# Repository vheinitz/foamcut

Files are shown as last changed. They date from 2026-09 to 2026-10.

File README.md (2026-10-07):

# foamcut — GT2560 XYUV hot wire cutter, bring-up project

A test bootstrap for a 4 axis hot wire foam cutter running on a Geeetech
GT2560. Two independent towers, four axes: **X/Y** on the left tower, **U/V**
on the right. Firmware is [grbl-Mega-5X](https://github.com/fra589/grbl-Mega-5X)
with a GT2560 pin map written for this project.

Nothing here needs the machine to exist yet — `make test` runs 77 checks
offline, including a cross-check that the two firmwares' pin maps describe the
same physical board.

```
make deps && make test          # offline
make grbl-flash                 # the one firmware, docs/bringup.md step 3
foamcut settings apply config/grbl_settings_foamcut.txt
foamcut setup                        # step 4: measure, no limit switches needed
foamcut run gcode/02_taper.nc
```

Follow **[docs/bringup.md](docs/bringup.md)** in order. It is written so that a
failure at any step can only have been caused by that step.

## Why not the obvious options

**Not RAMPS.** The GT2560 is a Mega 2560 with the driver sockets and MOSFETs on
the same PCB, but it is *not* RAMPS pin compatible. `motor_test/motor_test.ino`
in this directory is an example of the failure mode: it drives RAMPS pin
numbers (D54/D55/D38 for X) on a board whose X driver is on D25/D23/D27, so
nothing moves and nothing reports an error. The correct plain-Arduino sketch
is [`gt2560_motortest/`](gt2560_motortest/). See
[docs/gt2560_pinout.md](docs/gt2560_pinout.md).

**Not Marlin.** Marlin plans one E axis per move, so `X Y Z E` gives you four
simultaneous axes only if you accept that the fourth is an extruder with
extruder semantics — `M92`/`T0`/`M83`, no `U`/`V` letters, no `G28` per tower,
and no G-code generator that emits it. The `Marlin/` tree here is configured
that way (`EXTRUDERS 2`, `BOARD_GT2560_REV_A_PLUS`) and is kept as a reference,
but a foam cutter wants XYUV, not XYZE.

**Not the reference repo's firmware.** [rahulsarchive/4AxisFoamCutter](https://github.com/rahulsarchive/4AxisFoamCutter)
is a good build log and its notes on wire temperature, feed rate and G-code
generators are worth reading. It contains no firmware source, though — it
points at a grbl 0.8c2 fork for Mega/RAMPS. grbl-Mega-5X is the maintained
descendant of that idea, handles up to 6 axes, and lets the axis letters be
renamed, which is how this build gets real `U` and `V` words.

## Layout

| path | what |
|---|---|
| `firmware/hwtest/` | Bring-up fallback only: bit-bangs pins without a planner, for a board that shows no sign of life. Normal operation runs grbl exclusively. |
| `gt2560_motortest/` | Plain Arduino `.ino` with the correct GT2560 pins: pick X/Y/Z/U on the console, set microstepping, bounce motors. No PlatformIO needed. |
| `firmware/grbl5x/` | `build.sh` fetches grbl-Mega-5X, `configure.py` applies the XYUV/GT2560 overlay, then it builds and flashes. Every patch is anchored and verified, so an upstream change fails loudly instead of producing a firmware with a wrong pin map. |
| `firmware/grbl5x/overlay/cpu_map_gt2560.h` | the GT2560 pin map for grbl |
| `config/grbl_settings_foamcut.txt` | `$` settings, commented, with `MACHINE` marking every value you must measure |
| `host/` | the `foamcut` command line tool and its tests |
| `host/foamcut/qt/` | the PyQt6 interface; the masks are Qt Designer files in `qt/ui/*.ui` (loaded with `uic.loadUi`), dynamic widgets such as the mm canvases go into named placeholder layouts/splitters; `config/ui_state.json` remembers the last wing values, program and page |
| `gcode/` | test programs, from a single axis bounce to a tapered block |
| `airfoil/` | 295 airfoil `.dat` files (UIUC database via swarfer.co.za); instead of a file name, a four digit NACA number (`2412`) or its three numbers (`2 40 12` = camber %, position %, thickness %) can be typed and is computed |
| `config/beispiel.wing` | wing spec template, matches the measured travel |
| `config/beispiel.shape` | free-shape spec template (fuselage segment, ring) |
| `config/beispiel.contour`, `beispiel.svg` | SVG outline spec: ring, triangle and an "A" with its hole |
| `config/beispiel.slices`, `beispiel.stl` | slab spec: a 200 mm fuselage body in 40 mm slices |
| `docs/` | pinout and bring-up checklist |

## The `foamcut` tool

Two ways to run it, both identical:

```bash
./foamcut probe                      # wrapper in the checkout, no install needed
pip install --user -e host      # once; then plain `foamcut probe` from anywhere
```

```
foamcut check FILE          validate G-code offline: unsupported codes, missing
                       feeds, Z words on an XYUV machine, extents, run time,
                       and travel against config/machine.json
foamcut setup               measure the machine: axis mapping, steps/mm, direction,
                       manual reference, travel  -> config/machine.json
foamcut ref                 manual referencing after every power-up (no switches)
foamcut home                homing on the switches, work origin = switch + offset
foamcut homing show|set     limit switch config: NO/NC, pull-off, per-axis offset
                       and length (typed, not driven); saved in machine.json
foamcut jogpad              keyboard jogging
foamcut gui                 mouse jog pad, reference/travel buttons, hot wire,
                       load + play a G-code file with pause/stop
foamcut sim FILE       both carriage paths drawn turtle-style, no hardware
                       (also in the GUI: "Simulation" next to Start)
foamcut wing SPEC.wing      wing panel: root/tip airfoil + chords, panel length,
                       sweep, washout, mirror -> one-pass XYUV G-code
                       (root always at the fixed-wire tower, `machine set --wire-fixed`;
                       block face and table top are the anchors, lead-in runs
                       inside the foam, margins give the minimal block, the
                       tool reports the allowed table height range and extent;
                       chords from area + taper; optional aileron hinge cut)
                       (GUI "Flügel…": form with validated fields, live preview,
                       stale-program warning; foamcut wing --template for the text form)
foamcut shape SPEC.shape    free shape in one pass: rounded rectangle / triangle /
                       circle / ellipse on each side, disc or ring (slit at the
                       rear), same placement as wings (GUI page "Formen";
                       foamcut shape --template)
foamcut contour SPEC.contour  outlines of an SVG (letters, silhouettes, sketches from
                       Inkscape) cut prismatically, X=U / Y=V: kerf, slits to holes,
                       several pieces routed around each other (GUI page "Kontur";
                       foamcut contour --template)
foamcut wing|shape SPEC --stl [FILE]  also write the part as a body (STL),
                       spar slots and holes included, ready to be sliced into ribs
foamcut slices SPEC.slices  one slab of an STL body: side A = section at the slab's
                       start, side B at its end, lofted (smooth stack instead of
                       steps); or prismatic through the middle. Fuselages, big
                       wings from foam slices on spars (GUI page "Scheiben")
foamcut esp ls|put|start|status|pause|resume|abort
                       programs held by an ESP32 running ESP3D in front of the
                       board (docs/esp32.md); --port tcp://host uses its bridge
foamcut nest LIST.batch     several saved parts stacked in one block, one program
                       (GUI page "Schachteln"; pairs: mirror-image panel nested
                       thin-over-thick; wire travels behind the block face)
foamcut gen square|taper|bounce
foamcut selftest            move every axis out and back, verify it came home
foamcut settings dump|apply
foamcut jog AXIS DIST
foamcut wire 0..255
foamcut run FILE            stream, stopping on the exact line that failed
foamcut console
```

`check` and `gen` need no hardware. `check`, `run` and the GUI translate
generator output on the fly (`foamcut convert` writes the result to a file):

| generator | axis letters | handled |
|---|---|---|
| hotwireairfoil.coolpixx.de | `X Y A Z` (A horizontal, Z vertical) | A→U, Z→V, `G64` dropped, `F` added after `G94`, `M3 S1` → real wire power |
| Jedicut, WingGcode | `X Y U V` | unsupported header codes reported |
| LinuxCNC style | `X Y Z A` | `--format XYZA` |

`G93` inverse time feed is passed through — grbl supports it.

## Two things that will bite you

**The bed MOSFET cannot drive the wire under grbl.** D4 is on timer 0, which
grbl uses for the step pulse reset interrupt. The wire PWM is on D3 (timer 3)
instead — a hotend-sized MOSFET, about 40 W. For a metre of nichrome, use D3 to
gate an external MOSFET and keep the current off the board.

**The feed rate is a four axis vector.** With `N_AXIS_LINEAR = 4`, `F300` on a
move where both towers travel 100 mm gives each tower 212 mm/min, not 300.
`foamcut check` flags this per file.

## Licence

`firmware/grbl5x/overlay/` and `configure.py` derive from grbl-Mega-5X and are
GPLv3. The rest is yours to do as you like with.

## Erster Testlauf

```bash
make hwtest-flash     # Selbsttest-Firmware aufs Board
foamcut probe              # welcher Port, welche Firmware antwortet
foamcut hwtest             # gefuehrter Durchlauf, Pruefprotokoll am Ende
```

`foamcut hwtest` fragt nach jeder Achse nach, ob sie sich bewegt hat — die Firmware
kann Schritte zaehlen, aber nicht sehen, ob sich die Welle gedreht hat. Bei
"nein" grenzt er die Ursache ein: Spulenpaare vertauscht, Treiber verkehrt
herum, Vref auf null, oder STEP-Signal fehlt.

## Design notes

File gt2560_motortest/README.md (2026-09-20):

# gt2560_motortest — einfacher Arduino-Sketch fuer 4 Motoren

Ein einzelnes `.ino`, das die vier Motoren eines Geeetech **GT2560 Rev.A /
Rev.A+** (ATmega2560) ohne jede Library testet. Es ist das "plain Arduino
IDE"-Gegenstueck zu `firmware/hwtest/` (PlatformIO, mit Endschaltern und
Heizdraht) — nur STEP/DIR/EN, ein Menue auf der seriellen Konsole, fertig.

Das GT2560 ist **nicht** RAMPS-pinkompatibel. Die Pins sind aus
`Marlin/Marlin/src/pins/mega/pins_GT2560_REV_A(_PLUS).h` uebernommen:

| Achse | Board-Slot | STEP | DIR | EN |
|---|---|---|---|---|
| X | X  | D25 | D23 | D27 |
| Y | Y  | D31 | D33 | D29 |
| Z | Z  | D37 | D39 | D35 |
| U | E0 | D43 | D45 | D41 |
| E | E1 | D49 | D47 | D48 |

`E` ist der Reserve-Slot E1 — praktisch, wenn z.B. der E0-Steckplatz kaputt
ist (Motor umstecken, `a e` auswaehlen, testen). Wenn Deine Achsen X/Y/U/V
heissen statt X/Y/Z/U, aendere nur die Buchstaben in `AXIS_NAME[5]`.

## Flashen

**Arduino IDE:** Board = *Arduino Mega or Mega 2560*, Processor =
*ATmega2560*, Port = der GT2560-USB-Port. Dann hochladen.

**arduino-cli:**

```bash
arduino-cli compile --fqbn arduino:avr:mega gt2560_motortest
arduino-cli upload  --fqbn arduino:avr:mega -p /dev/ttyUSB0 gt2560_motortest
arduino-cli monitor -p /dev/ttyUSB0 -c baudrate=115200
```

## Konsole (115200 Baud)

Ein Befehl pro Parameter, mehrere Befehle pro Zeile mit `;` getrennt —
z.B. `a x; m 16; +; -`. Zeilenende ist egal (LF, CR oder auch nur eine
Tipppause von ~1 s).

| Befehl | Wirkung |
|---|---|
| `a x` / `a y` / `a z` / `a u` / `a e` | Achse auswaehlen (auch `a 0`..`a 4` = Slot; `e` = E1) |
| `+` / `-` | ausgewaehlte Achse vor / zurueck. Ohne Zahl: 200 × Mikrostepping = 1 Umdrehung |
| `+ 3200` / `- 3200` | ... alternativ mit expliziter Schrittanzahl |
| `m 1` ... `m 64` | Mikrostepping (Jumper-Stellung angeben: 1, 2, 4, 8, 16, 32, 64) |
| `u 2000` | Schrittperiode in µs (HIGH+LOW, min 20; groesser = langsamer). Mit Anlauf-Rampe. |
| `b` | ausgewaehlte Achse hin und zurueck (optional `b 3200`) |
| `t` | alle 4 Achsen **nacheinander** testen (optional `t 3200`) |
| `g` | alle 4 Achsen **gleichzeitig** (optional `g 3200`) |
| `e 1` / `e 0` | Treiber aktivieren (Motoren fest) / freigeben |
| `?` | aktuelle Parameter anzeigen |
| `h` | Hilfe |

Beim ersten `+`/`-`/`b`/`t`/`g` werden die Treiber automatisch aktiviert.

## Mikrostepping ist Jumper-Sache

Bei A4988/DRV8825 (MS1/MS2/MS3) und TMC2209 (MS1/MS2) wird das
Mikrostepping durch die **Jumper unter dem jeweiligen Treiber-Steckplatz**
eingestellt — nicht per Software. `m 64` sagt dem Sketch nur, welche
Jumper-Stellung Du gesteckt hast, damit er weiss, dass eine Umdrehung
200 × 64 = 12800 Schritte sind.

**TMC2209** (MS-Jumper):

| MS1 | MS2 | Mikrostepping |
|---|---|---|
| offen | offen | 1/8 |
| zu | offen | 1/32 |
| offen | zu | 1/64 |
| zu | zu | 1/16 |

Dein Fall: **MS2 zu, MS1 offen → `m 64`**.

### Warum "schnell" trotzdem langsam wirkt

- Eine Umdrehung sind bei 1/64 **12800 Schritte** — viermal mehr als bei 1/16.
  Bei gleicher Schrittfrequenz dreht der Motor also viermal langsamer.
- Der Sketch faehrt jetzt mit **Anlauf-Rampe** los (startet langsam und
  beschleunigt). Ohne Rampe stallen die Motoren bei kleinen Perioden und
  drehen nur langsam/ruckelnd weiter.
- Unter ~200 µs Periode brauchst Du genug Treiberstrom, sonst stallen die
  Motoren beim Anlauf trotz Rampe.

Vor dem ersten Fahren den Treiberstrom einstellen: Trimmer des Treibers erst
herunterdrehen, bis der Motor stehen bleibt, dann wieder hoch, bis er sauber
laeuft — und nicht weiter. Ein Motor, der heiss wird, bekommt zu viel Strom.

Dreht ein Motor nur brummt aber nicht, siehe `docs/bringup.md` ("Motor
brummt, dreht aber nicht"): meist sind die Spulenpaare im Stecker verschraenkt.

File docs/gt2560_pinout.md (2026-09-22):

# GT2560 pinout for a 4 axis XYUV hot wire cutter

**The GT2560 is not RAMPS pin compatible.** A RAMPS sketch flashed onto a
GT2560 toggles pins that are not connected to the drivers, so nothing moves and
nothing complains. The simplest correct Arduino sketch is
`gt2560_motortest/`; the full self test is `firmware/hwtest/`. Every number
below comes from the Geeetech Rev.A schematic
by way of Marlin's `pins_GT2560_REV_A.h`, and both firmwares in this repo are
checked against each other by `host/tests/test_pinmap.py`.

| | RAMPS 1.4 | GT2560 Rev.A |
|---|---|---|
| X STEP | D54 (A0) | **D25** |
| X DIR  | D55 (A1) | **D23** |
| X EN | D38 | **D27** |

## Axis assignment

The machine has two independent towers. Their four axes map onto the board's
five driver slots like this:

| axis | tower | slot | STEP | DIR | EN | MIN limit (fitted) | MAX limit (free) |
|---|---|---|---|-----|----|---|---|
| X | left, horizontal  | X  | D25 / PA3 | D23 / PA1 | D27 / PA5 | D22 / PA0, **X-MIN** connector | D30 / PC7 (Z-MIN) |
| Y | left, vertical | Y  | D31 / PC6 | D33 / PC4 | D29 / PA7 | D24 / PA2, **X-MAX** connector | D32 / PC5 (Z-MAX) |
| U | right, horizontal | Z  | D37 / PC0 | D39 / PG2 | D35 / PC2 | D26 / PA4, **Y-MIN** connector | D38 / PD7 (EXP2-7) |
| V | right, vertical | E0 | D43 / PL6 | D45 / PL4 | D41 / PG0 | D28 / PA6, **Y-MAX** connector | D40 / PG1 (EXP2-5) |

The four switches (normally closed, between S and GND, all at the negative end
of their axis) were wired to the X and Y connector pairs on 2026-09-18 and the
pin map follows that: every limit input sits on PORTA.

**EXP1 pins 1/2 are D18/D19 = TX1/RX1 (UART1).** That is where an ESP32
running ESP3D talks to grbl when the firmware is built with `SERIAL=esp`,
see `docs/esp32.md`.

The E1 slot is free. Keep a spare A4988 in it: when one driver dies you can
move a motor over and change four lines instead of waiting for a delivery.

## Outputs

| function | pin | notes |
|---|---|---|
| hot wire PWM, `M3 S…` | D3 / PE5 | HEATER_1 MOSFET, OC3C |
| hot wire hard enable, `M3`/`M5` | D2 / PE4 | HEATER_0 MOSFET, for a contactor |
| board fan, `M8`/`M9` | D7 / PH4 | FAN output |
| spindle direction (unused) | D5 / PE3 | |
| probe | D69 / PK7 | |

### Why the hot wire is on D3 and not on the bed MOSFET

The bed output (D4 / PG5) is the beefiest MOSFET on the board and the obvious
choice, but D4 is OC0B — **timer 0, which grbl uses for the step pulse reset
interrupt**. Taking it over for PWM breaks step generation. The heater outputs
D2 and D3 are on timer 3, which grbl leaves alone, so D3 gets the wire.

That MOSFET is sized for a hotend, roughly 40 W at 12 V. **A metre of 26 AWG
nichrome wants far more than that.** For anything beyond a short wire, use D3
as the gate signal for an external MOSFET or an adjustable DC-DC converter and
keep the wire current off the board entirely. The GT2560 in the reference
project died from exactly this class of thermal abuse.

## Two things the GT2560 cannot do

**No pin change interrupt on any endstop input.** The endstop pins live on
PORTA and PORTC, and on the ATmega2560 only PORTB, PE0, PORTJ and PORTK have
pin change interrupts. grbl's hard limit ISR therefore cannot be wired up.
grbl-Mega-5X's fallback is `ENABLE_RAMPS_HW_LIMITS`, which polls the switches
inside the stepper interrupt; it is left off in `config.h` and costs some
maximum step rate when you turn it on. Homing (`$H`) polls the switches
directly and works either way.

**Only three endstop connector pairs for four axes.** With one switch per axis
the X and Y pairs (MIN and MAX each) cover all four; the Z pair, EXP2 pin 7
(D38, SD detect) and EXP2 pin 5 (D40) stay free for optional far-end switches.
All limit inputs are internally pulled up, so an unwired input reads "not
triggered".

## Control inputs (reset / feed hold / cycle start / door)

grbl wants these four on one pin change capable port that carries no other
inputs. On a GT2560 that leaves only PORTK, and A8..A10 there are the thermistor
dividers, so the map uses **A11..A14** and the probe uses A15. None of these are
on a connector — you would have to solder to the MCU pads. Left unwired the
internal pull-ups keep all four inactive, which is the intended default.

## GT2560 V3 / V4

Different board, different pins — the V3 swaps X and Z and moves the endstops.
`firmware/hwtest` handles it (`pio run -e v3`); the grbl `cpu_map_gt2560.h` is
Rev.A only. Check `Marlin/Marlin/src/pins/mega/pins_GT2560_V3.h` and adapt if
that is what you have.

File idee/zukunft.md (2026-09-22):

# Wohin es hinausgeht – Notizen (nicht umgesetzt)

Stand 2026-09-17. Nur Ideen zum Festhalten; Reihenfolge ohne Priorität.

## Rumpf schneiden
- Rumpfsegmente als Schaumblöcke mit dem Draht schneiden (Seitenriss + Aufriss
  als zwei Schnitte, Block dazwischen wenden).
- Aufnahmen für Flügelposition (hoch/mittel/tief), Leitwerksabstand und
  Ballast im Rumpf gleich mit einplanen (Stiftlöcher/Nuten im Schnitt).

## Ruderwerke
- Höhen-/Seitenleitwerk als eigene Profile (symmetrisch, NACA 00xx) mit
  Rudertrennung; Leitwerksflächen aus den Faustregeln (HLW 25 %, SLW 10 % der
  Tragfläche) direkt aus der Flügelspezifikation ableiten.
- Ruderscharnier (Folienscharnier / V-Nut) als Schnittoption.

## Flügel gleicher Fläche, unterschiedlicher Form
- Formfamilie bei fester Fläche S und Spannweite b: Rechteck (λ=1),
  Trapez (λ 0,5–0,7), Ellipsen-Näherung (mehrere Trapezsegmente),
  Vorwärts-/Rückwärtspfeilung.
- Generator: Eingabe S, b, λ → c_root, c_tip; Ausgabe als Segmentliste, die die
  Maschine (≤ 200 mm Tiefe, ≤ ~450 mm Panel) einzeln schneiden kann.

## Segmentierungsplanung
- Automatische Aufteilung eines Flügels in Segmente nach Blocklänge/Verfahrweg,
  mit Stiftlöchern (Spar-Schnitt) an den Trennstellen und Nummerierung.
- Übersicht/Schnittplan (welches Segment aus welchem Block, welche Seite),
  Materialbedarf.

## 5. Achse: Heißnadel-Gantry
- Dünner Heißstift/Heißnadel zwischen den Türmen statt Draht, leicht abnehmbar
  (z. B. an zwei starken Magneten geklemmt) → Maschine wird zum XY-Gantry für
  Flächenschnitte: Öffnungen/Zwischenräume in Flügeln ausschneiden, danach mit
  Folie bespannen (Rippenflügel-Optik, Gewicht sparen).
- Softwareseitig: 2-Achs-Modus (X/Y oder X/U synchron), 2D-Kontur aus
  SVG/DXF, Nadel-Ein/Austauchen als Z-Ersatz (Vorschub-Pause/Draht aus).
- Firmware bleibt unverändert; nur Host-Seite.

## Steuerung ohne Rechner
- WLAN-fähiger Controller am GT2560 (ESP32 als seriell-WLAN-Brücke, sonst
  Raspberry Pi mit dem Host), damit die Maschine draußen ohne angeschlossenen
  Laptop läuft; Programme per Browser/Handy übertragen und starten.
  Idee vom 2026-09-21 (Valentin). Umgesetzt am 2026-09-22 als ESP32 + ESP3D:
  grbl-Variante UART1, `tcp://`-Verbindung, Job-Kopfzeile, Programmseite
  `esp32/foamcut.html`, CLI `foamcut esp` – siehe `docs/esp32.md`; Hardware
  noch nicht angeschlossen, Prüfliste dort.

## Schnittbreite abhängig von Geschwindigkeit (und Leistung, Schaum, Temperatur)
Idee vom 2026-09-21 (Valentin): „Wenn man die Kalibrierung mit einem
Styroportyp vorm Schneiden macht, mit unterschiedlicher Geschwindigkeit
schneidet und dann die Schnitte misst, kann man die Parameter approximiert
anwenden und in Erzeugung von G-Code berücksichtigen … da wo eine Seite viel
kleiner, fährt der Draht viel langsamer und Schnitt wird noch größer → Teilende
kleiner.“

Einschätzung (Claude, 2026-09-21):
- Physik: Kanalbreite wächst mit der Energie je Weg, grob `kerf ≈ a + b·P/v`.
  Beim Trapezflügel läuft die Endseite mit `v_tip = v_root · c_tip/c_root`
  (gleiche Zeit, kürzerer Umfang). Bei λ = 0,6 bekommt das Ende 1,67× Energie
  je mm; aus 1,0 mm Kerf werden dort erfahrungsgemäß eher 1,4–1,6 mm.
- Wirkung am JuFo-Flügel (Tiefe 160 mm, Dicke 10 % = 16 mm): Tiefe −0,5 mm
  (0,3 %, egal), Dicke −0,5 mm (3 %) – spürbar erst bei dünnen Profilen
  (≤ 8 %) oder starker Zuspitzung (λ < 0,5); dort wird auch die Endleiste
  fragil. Für Rechteckflügel und Formen mit gleich großen Seiten: nichts.
- Profis: ja, das gibt es. GMFC (Gilles Muller) rechnet den Kerf je Seite aus
  einer gemessenen Kerf-über-Geschwindigkeit-Tabelle; Jedicut hat Kerf je
  Seite; Industriemaschinen regeln eher den Drahtstrom mit der Bahngeschwindigkeit
  (konstante Energie je Weg). Letzteres hilft hier nicht: ein Draht, zwei
  Geschwindigkeiten – Leistung je Seite lässt sich nicht trennen, also bleibt
  nur die Geometriekorrektur je Seite.
- Umsetzung in foamcut ist klein: `_profile_mm()` nimmt den Kerf schon je
  Profil; nötig sind (1) Kalibrierschnitt: 2–3 gerade Schnitte bei v1, v2, v3
  (Freischnitt), Breiten messen, als `kerf_table` in machine.json, (2) im
  Generator Kerf je Seite aus `v_seite` interpoliert (linear in 1/v), (3) der
  Freischnitt-Dialog bekommt „Kalibrierung“. Grbl-seitig nichts.
- Empfehlung: erst machen, wenn ein Flügel mit λ < 0,6 oder ein dünnes
  Leitwerk gebraucht wird; bis dahin genügt der eine Kerf vom Maschinenblatt,
  gemessen bei der üblichen Geschwindigkeit.

## Langsam schneiden für glatte Oberfläche
Idee vom 2026-09-21 (Valentin): absichtlich langsamer fahren, damit die
Oberfläche länger schmilzt und glatter wird; G-Code soll das berücksichtigen
(größer schneiden) und Stege stehen lassen, damit das Teil nicht gleich absinkt.

Einschätzung (Claude, 2026-09-21):
- Begriff: Stehenbleibende Brücken heißen beim Schneiden „Haltestege“ (engl.
  tabs/bridges, wie beim Lasern); „Stützstrukturen“ sind 3D-Druck-Supports.
- Glatt wird XPS (Styrodur) durch langsam+heiß tatsächlich (verglaste Haut);
  EPS (Styropor) wird eher grubig, weil die Kugeln unterschiedlich schmelzen.
  Kosten: größerer Kerf, dünne Endleiste schmilzt weg, mehr Drahtdurchhang.
  „Größer schneiden“ ist dabei kein eigenes Feature, sondern genau der Kerf
  bei dieser Geschwindigkeit (siehe oben) – die Vorschubfelder gibt es schon.
- Haltestege: beim Flügel unnötig – der Kern liegt bis zum Schluss auf dem
  unteren Rest, der obere Rest liegt auf dem Kern, nichts fällt auf den Draht.
  Nützlich bei Formen mit Loch (Innenstück fällt beim Schließen der Kontur)
  und bei gestapelten Teilen. Umsetzung billig: Schließsegment um `steg` mm
  verkürzen, Steg per Hand brechen; ein Feld in [schnitt] der Form.
- Empfehlung: Haltesteg für Formen ja (klein; umgesetzt 2026-09-22 als `tab` für Kontur/Scheibe prismatisch); „langsam für glatt“ als
  Einstellung nur mit dem kalibrierten Kerf sinnvoll, sonst wird das Teil
  bloß kleiner. Für die Baukastenflügel eher Papier/Folie als Haut
  (distilled.md §5) statt Verglasung.

Messung 2026-09-22 (Valentin, Draht 15 Ω/m an 12 V, HEATER_1): 100 mm/min
statt 300 macht die Oberfläche **nicht** glatter, „eher rauer. Besser schnell
mit viel Power.“ Die Einschätzung oben („langsam+heiß = verglaste Haut“)
gilt für diesen Schaum/Draht also nicht; die Idee „langsam für glatt“ ist
damit vom Tisch. Was bleibt: Haltestege für Formen mit Loch.

## Freie 2D-Konturen und Scheiben aus STL
Idee vom 2026-09-23 (Valentin): „beliebige 2D-Formen ausschneiden: Buchstaben,
Freihandformen, Silhouetten, Skizzen … Achsen wie Gantry, Dicke egal … Eigener
Editor oder fertigen nutzen und als G-Code/Vektorgrafik importieren?“ Dazu
„3D-Form in Scheiben definierter Dicke schneiden und beliebige n-te schneiden
… riesige Flügel oder Rümpfe aus Styroporscheiben, Holzleisten, Bespannfolie
… Form als STL importierbar, hier definierbar wie dick die Scheibe und welche
gerade geschnitten werden muss.“

Einschätzung (Claude, 2026-09-23):
- Kein eigener Editor. Inkscape kann Text→Pfad, Bitmap nachzeichnen
  (Silhouetten, Skizzen), Freihand, Boolesche Operationen — das sind Jahre.
  Schnittstelle ist **SVG**, nicht G-Code: Laser-/Fräs-Postprozessoren heben
  zwischen Konturen ab (Laser aus, Eilgang) — ein Draht kann nicht abheben.
  Das Drahtspezifische bleibt bei foamcut: Kerf, Ein-/Auslauf von der
  Blockrückseite, Schlitz zu Innenkonturen (A, B, O), Reihenfolge, kein
  Eintauchen. Das Ring-Modell (shape.py) macht genau das schon für ein Loch.
- Neues Modell `.contour`: SVG-Datei + Maßstab + Lage im Block + Einlaufseite
  + Spiegeln; Pfade (Linien, Béziers) auf Polylinien plätten, Kerf-Offset,
  Lage prüfen gegen Verfahrweg (X ≤ 218, Y ≤ 130). Beide Seiten gleich
  (X=U, Y=V) — das ist ein Parallelschnitt (prismatisch), kein „Gantry“;
  Gantry bezeichnet die Bauform, nicht die Betriebsart. Aufwand ~1–2 Sitzungen,
  kleiner SVG-Parser reicht (kein svgpathtools nötig).
- STL-Scheiben: trimesh schneidet ein Netz mit Ebenen z = k·t und liefert die
  Konturen je Schnitt. Zwei Wege: (a) 3-Achs-Denke: Scheibe k = Kontur bei
  z_k, prismatisch → Treppen. (b) **Unser Vorteil**: Scheibe k als Loft
  zwischen Kontur z_k (Turm 1) und z_{k+1} (Turm 2) — wie das Formen-Modell
  mit Seiten A/B (`by_angle` für die Punktzuordnung) → glatte Regelfläche
  statt Treppen, ein Rumpf aus 40-mm-Scheiben sieht rund aus. Block = Scheibe,
  Konturen ≤ 218 × 130 mm je Seite; Rumpfquerschnitte passen, Flügel weiter
  mit dem Flügelmodell (das ist schon der Loft). Holmleisten brauchen Nuten
  vom Rand aus (Draht kann kein Loch ohne Schlitz), Position in allen Scheiben
  gleich, plus Nummerierung im G-Code-Kopf. Abhängigkeit trimesh + numpy.
  Aufwand ~2–3 Sitzungen nach dem SVG-Import, weil er dessen Kontur-Pipeline
  wiederverwendet.
- Reihenfolge: erst SVG-Kontur (prismatisch, sofort nützlich), dann
  STL-Scheiben mit Loft.
- Umgesetzt am 2026-09-22: Seiten „Kontur“ (`.contour`, SVG) und „Scheiben“
  (`.slices`, STL, verlaufend oder prismatisch), beide auch im Schachteln.
  Holmnut (oben/unten, Körperkoordinaten) und Haltesteg (`tab`, Kontur und
  prismatische Scheibe) ebenfalls drin.

## Drahttemperatur messen und regeln
Idee vom 2026-09-23 (Valentin): „die Temperatur zu messen und zu regeln.
Wäre es machbar? Wie bringe ich T-Sensor an dem Draht an?“

Einschätzung (Claude, 2026-09-23):
- **Kein Sensor am Draht.** Ein Thermoelement oder NTC am Draht hätte Masse
  und Zug am 0,3-mm-Draht, liegt auf Drahtpotential (PWM in den ADC), wandert
  durch den Schaum und misst ohnehin nur seine Kontaktstelle. IR-Sensor
  (MLX90614) scheidet aus, weil der Messfleck bei 5 cm rund 1 cm groß ist und
  der dünne Draht darin untergeht – gemessen wird der Hintergrund.
- **Der Draht ist sein eigener Sensor:** R = U/I, und R steigt mit der
  Temperatur. Haken: NiCr 80/20 hat absichtlich einen winzigen
  Temperaturkoeffizienten, α ≈ 1e-4/K → +250 K bringen nur +2,5 % Widerstand.
  Mit einem 16-bit-Strom-/Spannungsmesser (INA226 + Shunt 0,05 Ω) sind das
  noch ~20 K Auflösung: für eine Regelung genug, für eine Temperaturanzeige
  in °C zu wenig. **Edelstahldraht (V2A, ~10 Ω/m) hätte α ≈ 1e-3/K**, also
  zehnmal mehr Signal – wer ernsthaft regeln will, wechselt das Material.
- **Regelziel:** nicht Temperatur, sondern (1) konstante Leistung U·I statt
  konstanter PWM – gleicht Netzteil- und Spannungsschwankungen aus; (2)
  konstanter Widerstand = konstante Drahttemperatur (Prinzip der
  Hitzdraht-Anemometrie, CTA). Stufe 2 gleicht genau das aus, was draußen
  stört: Kühlung durch Wind, Kälte und durch den Schaum selbst.
- **Wo anschließen:** nicht am Draht, sondern in der Zuleitung – Shunt in
  Reihe, INA226 misst Drahtspannung und Strom. Am GT2560 liegt I2C auf
  EXP1 Pin 4/6 (D20 SDA, D21 SCL), aber grbl liest es nicht; die drei
  Thermistoreingänge (A8/A9/A10, TEMP_0/1/BED) sind frei, aber ebenfalls für
  grbl unsichtbar – nur mit Firmware-Umbau nutzbar (für die
  *Umgebungs*temperatur ein NTC dort wäre die einfachste Variante).
- **Eleganteste Bauform: ein eigenes kleines Drahtregler-Modul** (ESP32-C3
  oder Arduino Nano, MOSFET, Shunt, INA226) zwischen Netzteil und Draht. Es
  liest **den PWM-Tastgrad von D3 als Sollwert** und regelt die tatsächliche
  Leistung bzw. den Widerstand darauf. Dann ändert sich an foamcut, grbl und
  ESP3D *nichts*: `M3 S…` bleibt die Schnittstelle, nur die Bedeutung wird
  von „Tastgrad“ zu „Sollwert“. Materialkosten ~20 €.
- **Sicherheit:** Regler braucht Strombegrenzung, Watchdog (PWM weg → aus),
  Drahtbruch-Erkennung (I = 0 bei P > 0) und eine Obergrenze, sonst glüht der
  Draht bei einem Regelfehler durch; bei 24 V sind an 10 Ω 58 W möglich.
- Empfehlung: Stufe 1 (konstante Leistung) bringt schon den größten Teil und
  ist in einem Abend gebaut; Stufe 2 lohnt sich, wenn die Maschine wirklich
  draußen steht. Zusammen mit dem geschwindigkeitsabhängigen Kerf (oben) wäre
  das die Kombination, die reproduzierbare Schnitte ergibt.

### Nachtrag 2026-09-23: echter Fühler an den Thermistoreingängen
Einwand Valentin: „gt2560 hat doch bereits 3 Eingänge für T-Sensoren … T-Sensor
würde ich am Draht binden und mit einem gut isolierten Keramik- oder
Asbestgehäuse umschließen.“ Der Einwand trifft – die Widerstandsmessung ist bei
NiCr tatsächlich zu grob, ein echter Fühler ist genauer. Bedingungen:

- **Kein Asbest.** In der EU seit 2005 verboten, Bearbeiten und Verbauen ist
  strafbar und die Fasern sind krebserzeugend. Ersatz mit gleicher Wirkung:
  Keramikfaser (biolöslich, „Superwool“), Glasfaserschlauch (bis ~550 °C),
  Glimmerplättchen, Keramik-Perlrohr (Thermoelementperlen).
- **Der Fühler darf nicht in den Schnitt.** Alles am Draht ist dicker als der
  Draht und würde durch den Schaum pflügen. Also **außerhalb der Blockbreite**
  binden, dicht am Turm mit dem festen Draht; er fährt mit dem Draht mit und
  bleibt in der Luft. Kapsel leicht halten (< 2 g), sonst hängt der Draht
  durch – das Gewicht am anderen Turm spannt ihn nur.
- **Fühler:** PT1000 (Dünnschicht, bis 500 °C) passt am besten – die
  GT2560-Eingänge TEMP_0/1/BED (A8/A9/A10, PORTK Bit 0–2, in unserer grbl-Map
  frei) haben schon 4,7-kΩ-Pull-ups nach 5 V. PT1000 an diesem Teiler: 0,88 V
  bei 0 °C, 1,72 V bei 400 °C → am 10-bit-ADC ~2,3 K je Schritt. Der
  Drucker-NTC (100 kΩ) ist nur bis 300 °C spezifiziert und oben sehr flach;
  ein Typ-K-Element bräuchte einen Verstärker (AD8495, 5 mV/°C – ebenfalls
  analog anschließbar) oder SPI (MAX31855, dann kein Thermistoreingang).
  Zwischen Draht und Fühler ein Glimmerplättchen: der Draht führt PWM.
- **Was der Fühler misst:** die Temperatur der Kapsel neben dem Turm, nicht
  die der Schnittstelle. Absolut ist das falsch, als *Regelgröße* aber
  reproduzierbar; die Zeitkonstante der Kapsel liegt bei Sekunden, was für
  langsame Störungen (Kälte, Wind, Netzteil) genau reicht.
- **Kette bis zur Regelung, ohne neue Hardware am Rechner:**
  1. grbl liest den ADC und hängt ein Feld an den Statusbericht, z. B.
     `|WT:212.5` (report.c, dort wo `|FS:` entsteht; ~40 Zeilen plus ein
     `$`-Setting für Fühlertyp und Kalibrierung).
  2. `parse_status()` im Host nimmt das Feld auf, die Maschinenseite zeigt es.
  3. Der Host regelt mit den Echtzeitbytes für den Spindel-Override:
     0x9C/0x9D = ±1 %, 0x9A/0x9B = ±10 %, 0x99 = zurück auf 100 %. Die wirken
     **mitten im laufenden Programm**, ohne G-Code zu ändern – ein PI-Regler
     mit ein paar Prozent je Sekunde genügt. `sys.spindle_speed` im Bericht
     zeigt, was tatsächlich eingestellt ist.
  Damit bleibt die Architektur wie sie ist: Firmware misst, Host regelt.
- Aufwand: Fühler + Kapsel ~15 €, Firmware ein Abend, Host ein Abend. Der
  Weg ist dem Regler-Modul (oben) vorzuziehen, solange der PC mitläuft; ohne
  PC (ESP32) müsste der Regler in die Firmware wandern.

### Nachtrag 2026-09-23: selbst gewickelter Fühler?
Idee Valentin: „ich wickele mit Stück solchen Drahts mein Heissdraht, davor
jedoch erhitze ich es und stecke ins Wasser. Es oxidiert und bildet eine
Stromisolierung. Welchen Draht nehme ich dafür mit großer R-Schwankung von T?“

- **Oxid als Isolator trägt nicht.** Abschrecken im Wasser sprengt den Zunder
  eher ab (Thermoschock), als dass es eine haftende Schicht bildet; Eisen- und
  Chromoxid sind bei Temperatur Halbleiter, keine Isolatoren. Die einzige
  brauchbare Eigenoxidschicht ist **Al₂O₃ auf Kanthal (FeCrAl)**, und die
  entsteht durch langsames Glühen bei ~1000 °C, nicht durch Abschrecken – beim
  Wickeln reißt sie an den Kontaktstellen trotzdem auf. Schon einige kΩ
  Nebenschluss zum PWM-Draht machen die Messung unbrauchbar. Also **Glimmer
  oder Glasfaserschlauch** zwischen Fühler und Draht, das ist dünn, sicher und
  kostet nichts.
- **Größter Temperaturkoeffizient bei bezahlbaren Drähten:** Nickel
  α ≈ 6000 ppm/K (+150 % bei +250 K!), Platin 3850 ppm/K (+96 %), Eisen
  ~5000, Kupfer 4300 (oxidiert über 200 °C), Edelstahl nur 1000 ppm/K.
  Nickeldraht wäre also das Material der Wahl – **aber**:
- **Die Länge killt die Idee.** Der Thermistoreingang des GT2560 hat einen
  4,7-kΩ-Pull-up; gut auflösbar ist ein Fühler von ~1 kΩ. Dafür bräuchte man
  bei 0,05 mm Nickeldraht **28 m** (Platin 18 m, Edelstahl 2,7 m). Ein paar
  Zentimeter um den Draht gewickelt ergeben 1–2 Ω, und 1–2 Ω an 4,7 kΩ sind
  im ADC nicht zu sehen – das bräuchte Brücke, Konstantstromquelle und
  Verstärker. Genau deshalb sind PT1000 **Dünnschicht-Mäander** und keine
  Wickel: 1 kΩ auf 2 × 2 mm.
- **Fazit:** Der Gedanke ist richtig (Draht als RTD), nur die Bauform nicht.
  Ein Dünnschicht-PT1000 (bis 500 °C, glaspassiviert = schon isoliert, ~2 €)
  bringt dasselbe in klein, linear und direkt am vorhandenen Eingang. Wer
  trotzdem selbst wickeln will: Nickeldraht **in Reihe zur Messbrücke**, nicht
  an den Thermistoreingang.

**Einkaufsliste, falls es gebaut wird** (Stand 2026-09-23, nichts davon
gekauft oder geprüft):
- Fühler: „PT1000 Dünnschicht Klasse B, 2 × 2 mm, bis 500 °C“ oder ein
  PT100-Sensorelement M222. **Keine keramischen PTC/Kaltleiter** (MZ-, PTC-
  „Posistor“-Serien): die sind Heizelemente und Schutzwiderstände, ihre
  Kennlinie ist bis zur Curie-Temperatur flach und springt dann um Zehnerpotenzen
  – damit lässt sich nichts messen. Prüfkriterium beim Kauf: gibt das
  Datenblatt eine R(T)-Tabelle oder -Kurve über den ganzen Bereich an?
- Isolation Draht ↔ Fühler: Glimmerplättchen (Mica) 0,1 mm.
- Kapsel: Keramikfaserpapier/-band (biolöslich, „Superwool“) 1–2 mm, außen
  Glasgewebeband (bis ~550 °C; selbstklebende Varianten halten nur ~200 °C,
  also besser binden statt kleben).
- Binden: Glasseidezwirn oder 0,2-mm-Edelstahldraht.
- Zuleitung: Keramik-Perlrohr oder Glasfaserschlauch über die Litzen,
  verdrillt und weg von der Heizdrahtleitung; ganze Kapsel unter 2 g.

## Sonstiges
- Karton-Prototypen-Bausatz (Lasercutter) parallel zum Schaumschneider.
- Winde mit Drehzahlregelung für reproduzierbare Rampenstarts.

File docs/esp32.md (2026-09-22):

# ESP32 vor dem Board: Programme ohne PC schneiden

Stand 2026-09-22, geschrieben ohne ESP32 in der Hand – gegen die
ESP3D‑3.x‑Dokumentation (esp3d.io) und den GT2560‑Schaltplan. Auftrag
(Valentin, 2026-09-21): „ESP32 kommuniziert über serielle mit dem GT2560, nimmt
die Aufträge von der Software und schneidet sie. Die Aufträge bleiben auf dem
ESP32 und können später auch ohne PC geschnitten werden. Die webbasierte SW
listet die Aufträge auf und sagt zu jedem, wie groß der Block sein soll und wo
er liegen soll.“ Abschnitt „Beim ersten Kontakt prüfen“ nennt, was am echten
Gerät noch zu verifizieren ist.

## Was wo läuft

| Teil | Aufgabe | Quelle |
|---|---|---|
| grbl‑Mega‑5X auf dem GT2560, Variante **UART1** | schneidet wie bisher; hört auf D18/D19 statt auf USB | `firmware/grbl5x`, `SERIAL=esp ./build.sh` |
| **ESP3D 3.x** auf einem ESP32‑DevKit | WLAN, Dateiablage im Flash, Streaming an grbl, Web‑Oberfläche, TCP‑Brücke (Port 23) | esp3d.io, fertig |
| `esp32/foamcut.html` im ESP‑Flash | Programmliste mit Block/Lage/Tisch/Laufzeit, Start/Pause/Abbruch | dieses Repo |
| `foamcut` auf dem PC | erzeugt Programme (Zeile 2: `; foamcut-job …`), lädt sie hoch (`foamcut esp put`), kann über `--port tcp://foamcut.local` weiter live fahren | dieses Repo |

Ohne PC heißt: **vorhandene Programme erneut schneiden.** Entwerfen (Flügel,
Formen, Kontur, Scheiben, Schachteln) bleibt am PC.

## Hardware

Ein ESP32‑DevKitC (WROOM‑32, 4 MB Flash) reicht; der Flash hält Dutzende
Programme (eine .nc hat 10–50 kB). SD‑Slot nur, wenn es hunderte werden.

### Verdrahtung – EXP1 des GT2560

grbl‑Mega‑5X hängt fest auf UART0, und UART0 ist beim GT2560 der USB‑Chip.
Die Variante `SERIAL=esp` verlegt grbl auf **UART1 = D18 (TX1) / D19 (RX1)**;
beide liegen auf dem LCD‑Stecker **EXP1**, Pin 1 und 2 (im Marlin‑Pinfile
`pins_GT2560_REV_A.h`: `EXP1_01_PIN 18 // TX1 / BEEPER`, `EXP1_02_PIN 19 //
RX1 / ENC`). EXP1 führt auch 5 V und GND (Pin 9/10 – am Stecker prüfen,
Aufdruck oder Multimeter).

```
GT2560 EXP1                      ESP32 DevKitC
Pin 1  D18 TX1 (5 V)  ──[2k2]──┬──  GPIO16 (RX2)
                             [3k3]
                               └──  GND
Pin 2  D19 RX1        ◄────────────  GPIO17 (TX2)      (3,3 V reicht dem Mega: V_IH = 3,0 V)
Pin 9/10  GND, +5 V   ───────────►  GND, 5V/VIN   (RepRapDiscount-Belegung: 9 = GND, 10 = +5 V; am Stecker pruefen)
```

- Spannungsteiler 2k2/3k3 am Mega‑TX: 5 V → 3,0 V, die ESP32‑Eingänge sind
  nicht 5‑V‑fest.
- ESP‑TX (3,3 V) direkt an RX1: über der Mega‑Schwelle von 3,0 V, knapp,
  aber gängige Praxis; wer sicher gehen will, nimmt einen Pegelwandler.
- Massen verbinden, kurze Leitungen (< 30 cm), 115200 Baud.
- USB des GT2560 danach nur noch für den Bootloader (Flashen); grbl meldet
  sich dort nicht mehr. Zurück zur USB‑Variante: `./build.sh flash`.

### Endschalter ohne PC

Der Schutz „Endschalter gedrückt während der Fahrt = Stopp“ sitzt heute im
Python‑Worker. Ohne PC gibt es ihn nur, wenn grbl ihn selbst hat:
`HW_LIMITS=1` beim Bauen (`ENABLE_RAMPS_HW_LIMITS`, Polling im
Stepper‑Interrupt, weil kein GT2560‑Endschaltereingang einen
Pin‑Change‑Interrupt hat) und dann `$21=1`. Kostet etwas maximale Schrittrate
– nach dem Umstellen die `MAX_STEP_HZ`‑Grenze (20 kHz, `machine.py`) mit
einem schnellen Eilgang nachprüfen. `$21` gehört danach in
`config/grbl_settings_foamcut.txt`.

## Firmware bauen und flashen

```bash
cd firmware/grbl5x
SERIAL=esp HW_LIMITS=1 ./build.sh          # -> vendor/grbl-esp.hex
SERIAL=esp HW_LIMITS=1 ./build.sh flash    # ueber USB flashen (Bootloader bleibt)
```

`configure.py` benennt dafür in `serial.c` die UART0‑Register in UART1 um
(`UDR0→UDR1`, `UCSR0A/B`, `UBRR0H/L`, `U2X0`, `RXEN0`, `TXEN0`, `RXCIE0`,
`UDRIE0`) und setzt die Interrupt‑Vektoren `USART1_RX_vect` /
`USART1_UDRE_vect` in `cpu_map_gt2560.h`. Die USB‑Variante bleibt
byte‑identisch (geprüft am 2026-09-22 gegen das geflashte `grbl.hex`).

## ESP3D einrichten

1. ESP3D 3.x für den ESP32 flashen (esp3d.io → „ESP3D 3.0“, Web‑Installer
   oder PlatformIO), Ziel‑Firmware **GRBL**.
2. Beim ersten Start spannt ESP3D ein WLAN auf; dort das eigene WLAN
   eintragen, Hostname **foamcut** (dann `foamcut.local`), serielle
   Geschwindigkeit **115200**, Telnet/TCP‑Brücke aktivieren (Port 23).
3. ESP3D‑WebUI aufrufen, Konsole: `$$` muss die grbl‑Settings zeigen. Dann
   `config/grbl_settings_foamcut.txt` einmal per PC einspielen:
   `foamcut --port tcp://foamcut.local settings apply config/grbl_settings_foamcut.txt`.
4. `esp32/foamcut.html` über die ESP3D‑Oberfläche (Dateien / Filesystem) in
   das Flash‑Wurzelverzeichnis laden; Seite: `http://foamcut.local/foamcut.html`.
   Aufs Handy als Lesezeichen.

## Betrieb

- Programm am PC erzeugen (jede Seite → „G‑Code speichern…“), dann
  `foamcut esp put gcode/teil.nc` (oder Upload in der ESP3D‑Oberfläche).
- Auf `foamcut.html`: Liste zeigt je Programm **Block L×H×B, Rückseite X,
  Tisch Y, Wurzelturm, Laufzeit, Schlittenweg** – alles aus Zeile 2 der Datei
  (`; foamcut-job block=… x=… y=… root=… time=… travel=…`). Programm
  antippen → Start (mit Rückfrage), Pause / Weiter / Abbruch, Fortschritt
  alle 2 s.
- Heizleistung: Programme tragen `M3 S<wert>` aus `machine.json`
  (`wire_power`); mit `wire_power = 0` steht `S1` im Programm und der Draht
  bleibt kalt, weil hier kein PC den Schieberwert einsetzt. Vor dem Upload
  also **Heizleistung auf der Maschinenseite setzen**.
- Live vom PC über den ESP: `foamcut gui` mit Port `tcp://foamcut.local`
  oder `foamcut --port tcp://foamcut.local run …`. Beim Verbinden wird das
  Board nicht resettet (anders als über USB), grbl behält die Position.
- CLI ohne Browser: `foamcut esp ls | put | start NAME | status | pause |
  resume | abort` (`--host` für einen anderen Namen/IP).

## Beim ersten Kontakt prüfen

Alles unten ist aus der Dokumentation abgeleitet; die Stellen im Code sind
klein und leicht anzupassen.

1. **Dateiliste**: `GET /files?path=/` liefert JSON mit `files[]` (`name`,
   `size`). Code: `esp.py::list_files`, `foamcut.html::loadList`.
2. **Dateiinhalt per URL**: `GET /<name>` muss die .nc aus dem Flash‑Wurzel­
   verzeichnis liefern (ESP3D bedient das Web‑Wurzelverzeichnis aus /FS).
   Falls nicht: Datei über `/files?path=/&action=…` oder `[ESP720]` lesen.
3. **Upload‑Formular**: `POST /files`, Felder `path`, `<name>S` (Größe),
   `myfiles` (Datei) – so sendet die ESP3D‑WebUI. Code: `esp.py::upload`.
4. **Start**: `/command?cmd=[ESP700]/<name>`; Zustand `[ESP701]json=yes`
   (`status`, `total`, `processed`); Steuern `[ESP701]action=PAUSE|RESUME|ABORT`.
5. **Telnet‑Brücke** auf Port 23 antwortet zeilenweise ohne Echo; sonst in
   `link.py::TcpLink` das Echo filtern.
6. **Authentifizierung** in ESP3D aus lassen (sonst `pwd=` an jedes Kommando).
7. **grbl‑Banner** über TCP: `connect()` schickt Ctrl‑X, wenn kein Banner
   wartet – ESP3D reicht das Byte 0x18 durch? Wenn nicht, `[ESP…]`‑Alternativen
   prüfen oder das GUI‑„Reset“ über die ESP3D‑Konsole machen.

## Offen / später

- Raspberry Pi Zero 2 W statt ESP32, falls auch das Entwerfen aufs Gerät soll
  (Python‑Host, Browser‑GUI) – anderer Umfang, andere Nachteile (Boot, SD).
- Heizleistung im Programm variabel (`wire_power_max`, Heizsperre), sobald 24 V
  am Board sind.

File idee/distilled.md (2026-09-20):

# Flugzeugbaukasten – Destillat der ChatGPT-Diskussionen

Extrakt aus den 8 Chats des ChatGPT-Projekts „Flugzeugbaukasten“ (März/April 2026,
Export in `idee/chat_*.html`). Alles hier sind **Hinweise und Ideen aus der
Planungsphase** – Flügelmaße, Blöcke, Materialien sind frei wählbar; fest ist nur
die Maschine (XYUV-Schaumschneider, X/U 220 mm, Y/V 100 mm, Turmabstand 615 mm).

## 1. Projektidee (JuFo)

- Modularer **„Lego-Flugzeug“-Baukasten** für Jugend forscht (Sohn, 16/17 J.;
  ~1 Jahr, ~2 h/Woche). Ziel: Schüler erkunden schnell, *was fliegt und was nicht*.
- Austauschbar/verschiebbar: Flügelsegmente, Flügelposition (hoch/mittel/tief),
  Flügelwinkel/EWD, V-Form, Leitwerksgröße und -abstand, Schwerpunkt (Ballast),
  ggf. Doppeldecker-Abstand.
- **Segmente**: Positionierstifte (Holz/Kunststoff, leicht konisch) für exakte
  Ausrichtung + dünne wiederlösbare Montagestreifen / flache Neodym-Magnete
  (≤ 3×1 mm) auf den Endrippen. Alles ≤ 1–2 mm Aufbau.
- Verbinder/Halter 3D-gedruckt (PETG, 10–20 % Infill, 2–3 Perimeter, 0,8–1,2 mm
  Wand → 5–8 g je Teil, gesamt ~35–40 g); Holm (Balsa/Kiefer/Carbon) trägt die
  Kräfte, Druckteile nur Position/Kraftübertragung.
- Startvorrichtung: **Rampe 1–2 m**, Antrieb nur für die Rampe (Gummi oder
  drehzahlgeregelte Winde → reproduzierbare Starts, beliebiges
  Beschleunigungsprofil). Winde: bei 150 g, 4 m/s², Ø 100 mm Rad: M ≈ 0,03 N·m,
  n ≈ 760 U/min, v_ab ≈ 4 m/s nach 1 s.
- Tests indoor (Ventilator mit Strömungsgleichrichter, 1,5–2 m Abstand),
  Fliegen draußen auf Wiese/Hügel. Rechtlich: < 250 g, ohne Kamera → keine
  Registrierung; Minderjährige formal unter Aufsicht (Erwachsener in Sichtweite
  reicht, Eigenleistung für JuFo bleibt glaubwürdig).

## 2. Zielklasse des Modells

| Größe | Wert |
|---|---|
| Spannweite | 0,5–0,8 m (Start: **70 cm**) |
| Flügelfläche | 12–18 dm² (Start: **15 dm²**) |
| Gewicht | 120–200 g (Start: **150 g**) |
| Flächenbelastung | **8–12 g/dm²** (indoor eher 10–15) |
| Streckung AR = b²/S | 4–6 klein, 7–8 guter Anfängersegler |
| Mittlere Tiefe | ~20 cm (→ passt an die Maschine: max ~200 mm Profiltiefe) |
| Wurzel/Spitze | λ = c_tip/c_root ≈ 0,5–0,7 (Start 0,6); z. B. 26 → 16 cm |
| Profildicke | 8–12 % der Tiefe (Start 10 %); dicker = gutmütiger |
| Schwerpunkt | 28–33 % der Wurzeltiefe ab Nasenleiste (Start 30 %) |
| EWD | 2–3° (Flügel +3°, HLW 0°) |
| V-Form | 3–6° je Seite (Start 4–5°) |
| Höhenleitwerk | 20–30 % der Tragfläche (Start 25 %), V_h ≈ 0,5–0,7 |
| Seitenleitwerk | 8–12 % der Tragfläche (Start 10 %), V_v ≈ 0,03–0,05 |
| Rumpflänge | 0,7–0,85 × Spannweite (Start 0,8) |
| Leitwerkshebel | 2–3 × mittlere Tiefe |

Schnellstart-Prototyp: b 70 cm, S 15 dm², c 26/16 cm, Rumpf 55 cm, HLW 3,5 dm²,
SLW 1,5 dm², Dicke 2 cm, SP 8 cm ab Nasenleiste, V-Form 5°, EWD 2–3°.

## 3. Formeln (ASCII, Python-tauglich)

```
S        = b * c_mean                 # Fläche
c_mean   = (c_root + c_tip) / 2
lambda   = c_tip / c_root             # Zuspitzung
c_root   = 2*S / (b*(1+lambda))       # bei gegebener Fläche
AR       = b**2 / S                   # Streckung
L        = 0.5 * rho * v**2 * S * CL  # Auftrieb, rho ~1.2 kg/m^3, CL 0.5..1.2
v_ab     = sqrt(2*m*g / (rho*S*CL))   # Abhebegeschwindigkeit (~3-4 m/s bei 150 g/15 dm^2)
loading  = m_g / S_dm2                # Flächenbelastung g/dm^2
V_h      = S_h*l_h / (S*c_mean)       # Leitwerksvolumen horizontal
V_v      = S_v*l_v / (S*b)            # vertikal
EWD      = wing_angle - tail_angle
Re       = rho*v*l / mu               # <50k kritisch, 50-150k Modellflug
CL_platte ~ 2*pi*alpha                # flache Platte, alpha in rad
```

Merksätze: Schwerpunkt geht vor Gewicht („lieber leicht kopflastig“); Fläche
allein reicht nicht – Streckung zählt; lang & schmal = langsam & stabil
(Hebelarm!), kurz & breit = schnell & wendig; Anstellwinkel bestimmt *wie viel*
Kraft, Profil *wohin* sie zeigt.

## 4. Aerodynamik-Erkenntnisse für die Experimente

- **Gleiche Fläche, andere Form** (Rechteck/Trapez/Ellipse, Spannweite vs.
  Tiefe) ist ein sauberes Experiment: Fläche vorher messen, gleiches Material,
  dann vergleicht man wirklich die Form.
- Flache Platte erzeugt Auftrieb allein durch Anstellwinkel; bei < 100 g dominiert
  der Anstellwinkel (~65 %) gegenüber dem Profil (~35 %), weil Re klein ist.
  Trotzdem: leicht gewölbt + dünn ist gutmütiger als flach.
- Unterseite flach („oben rund, unten flach“, Clark-Y-artig) reicht für langsame
  Segler; symmetrisch nur für Kunstflug.
- Stark verjüngt (λ < 0,5) → Spitzen reißen zuerst ab → Trudeln. Abhilfe:
  Schränkung (Washout) an der Spitze.
- Vorwärtspfeilung: gutes Langsamflugverhalten, aber aeroelastisch kritisch –
  mit Schaum nicht sinnvoll.
- Ente (Canard): beide Flächen tragen, kein Abtrieb am Heck → weniger Ballast,
  Schwerpunkt bei ~15–25 % (Start 20 %) statt 25–33 %; empfindlicher einzustellen.
  Dreiflächer möglich, aber komplex.
- Doppeldecker: Fläche = Summe, Abstand 0,6–0,8 × Tiefe, stabil, mehr Widerstand.
- Indoor: zu leichte Modelle „tanzen“ in der Luft – etwas Masse (≥ 120–150 g) und
  mittlere Größe (50–80 cm) machen Versuche reproduzierbar.

## 5. Materialien

| Material | Dichte | Bemerkung |
|---|---|---|
| EPS (Styropor) | 15–30 kg/m³ (~20 g/dm³) | leicht, weich, körnig; Kerne |
| XPS (Styrodur, blau) | 30–45 | glatter, steifer, spröde; Kerne/Profile – **Heißdraht** |
| Depron (extrudierter PS-Schaum) | ~40, 3–6 mm | glatt, biegsam, formbar; Beplankung, Leitwerke |
| Dekor-Deckenplatten | wie feines EPS/XPS | Baumarkt-Hack, spröde, oft beschichtet |
| Karton A3 1,8 mm | 4,6 g/dm² | billig, Lasercutter, ungiftig, Holzleim; braucht Rippen/Holm → **Prototypen-Bausatz aus Karton** |
| Balsa | 100–220 kg/m³ | Holme, Nasen-/Endleisten, 0,6–1 mm Streifen auf Rippen |
| Kiefer / Carbon | 400–550 / 1500+ | Holme |
| PLA/PETG | 1200–1300 | nur Verbinder (~8× schwerer als Balsa) |

Kleben auf Schaum: Weißleim, PU, Styroporkleber, Heißkleber vorsichtig – **kein**
Sekundenkleber/Lösungsmittel. Bespannung: Schrumpffolie (KAVAN/Oracover) bügeln
90–110 °C, schrumpfen 120–150 °C – **Styropor wird ab 70–80 °C weich**, also nur
mit Balsa/Papier-Schutzschicht oder Heißluft aus 30–60 cm; Reihenfolge
Nasenleiste → Endleiste → Holme → Randbogen, dann Felder, beide Seiten
abwechselnd, von der Mitte nach außen. Alternativ Packpapier + verdünnter
Holzleim (1:1) als steife Haut (+10–30 % Gewicht, 2–5× steifer).

## 6. Werkzeuge / Software

- NACA-4-Profile per Formel (m p tt: Wölbung %, Lage /10, Dicke %); Empfehlung
  NACA 2412 (gutmütig), 3412 (Kompromiss), 4412 (Auftrieb); Python-Skript mit
  benannten Konstanten und SVG/DXF-Export (ezdxf/svgwrite) liegt im Chat
  „Flugzeugparameter und NACA“; OpenSCAD-Rippen per Formel ebenfalls möglich.
  → In `foamcut` durch `airfoil/*.dat` + Wing-Generator abgedeckt.
- Ultraschall-Cutter (NeoBlade, ~130 €): gut für Supports/Pappe/Depron, für
  Balsa unnötig, Klinge wird warm, für Kinder nur mit Aufsicht; nicht unter den
  Tisch montieren.

## 7. Konsequenzen für `foamcut`

- Flügeltiefe ≤ 200 mm, Panel ≤ ~450 mm je Schnitt → Segmentschnitte sind der
  Normalfall; Segment-/Stiftlöcher-Workflow hat Vorrang.
- Formfamilien gleicher Fläche (Rechteck/Trapez/Ellipse-Approximation) als
  Generatoroption wären für die Experimente direkt nützlich.
- Flache Platte / dünne Profile (8–10 %) und Schränkung müssen sauber
  schneidbar sein (Kerf, Apex-Warnung bei starker Verjüngung).
- Aufspannung: Block liegt auf dem (höhen-/breitenverstellbaren) Tisch; die
  Software liefert je Schnitt Mindestblock, zulässigen Tischhöhenbereich und
  maximale Tischausdehnung (Stand 2026-09-17 umgesetzt).

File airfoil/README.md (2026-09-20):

# Profilkoordinaten

295 Profile im Selig-Format (`.dat`: Name in Zeile 1, dann x/y-Paare von der
Hinterkante über die Oberseite zur Nase und über die Unterseite zurück,
Sehne = 1.0), geladen am 2026-09-13 von

    https://swarfer.co.za/rc/foils/coord.php

Das ist der Spiegel der UIUC Airfoil Coordinates Database, auf den auch das
4AxisFoamCutter-Projekt verweist. Hinweis von dort: nicht alle Profile taugen
im Modellmaßstab — manche sind für manntragende Flugzeuge gerechnet
(Stichwort Reynoldszahl).

Neu laden:

    grep -oE "href='coord/[^']+\.dat'" <(curl -sL https://swarfer.co.za/rc/foils/coord.php) \
      | sed "s|href='|https://swarfer.co.za/rc/foils/|; s|'$||" \
      | xargs -P 4 -I{} curl -sS -f -L -O "{}"

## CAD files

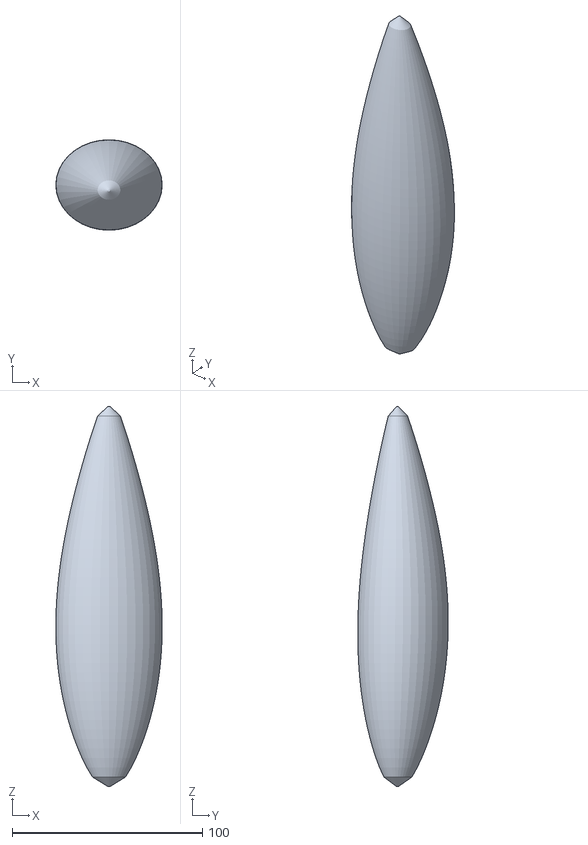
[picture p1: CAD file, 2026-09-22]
config/beispiel.stl
56.0 x 47.6 x 200.0

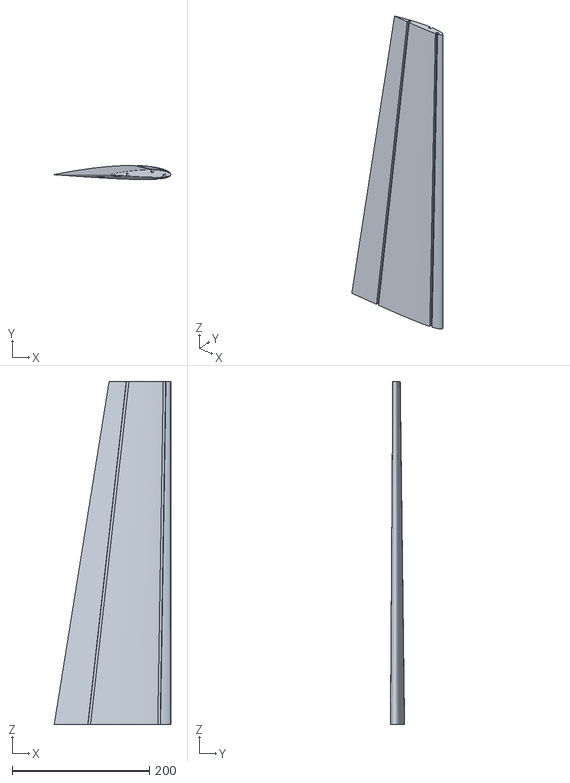
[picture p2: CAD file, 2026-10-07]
data/Fluegel2412_170_90.stl
170.0 x 20.7 x 500.0

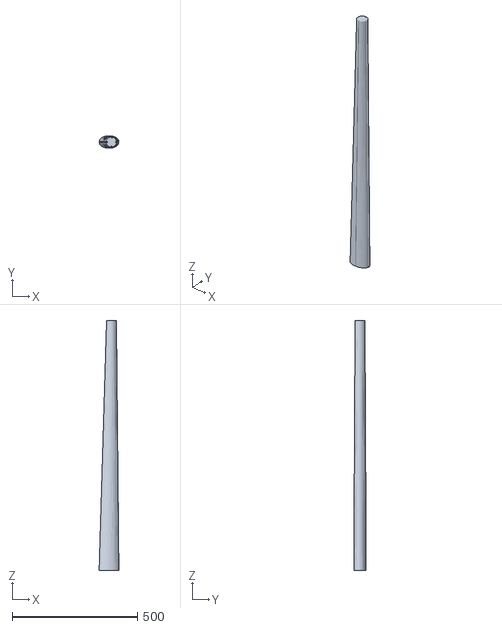
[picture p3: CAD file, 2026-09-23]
data/rippen2.stl
79.4 x 49.9 x 1000.0

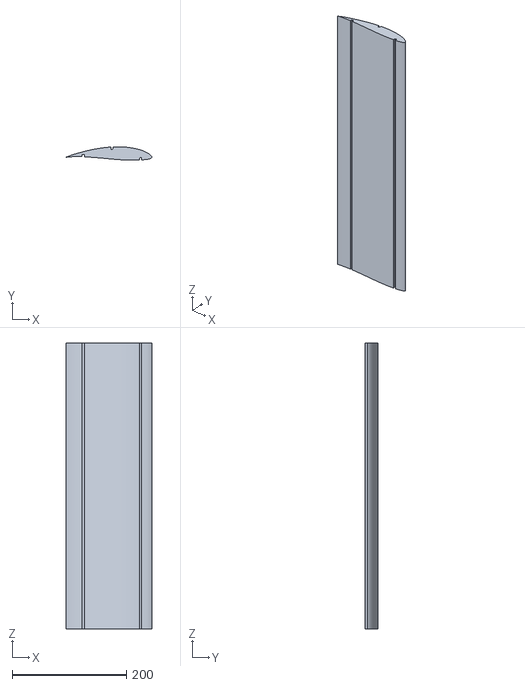
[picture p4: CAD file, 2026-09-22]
data/rippen.stl
149.9 x 23.4 x 500.0

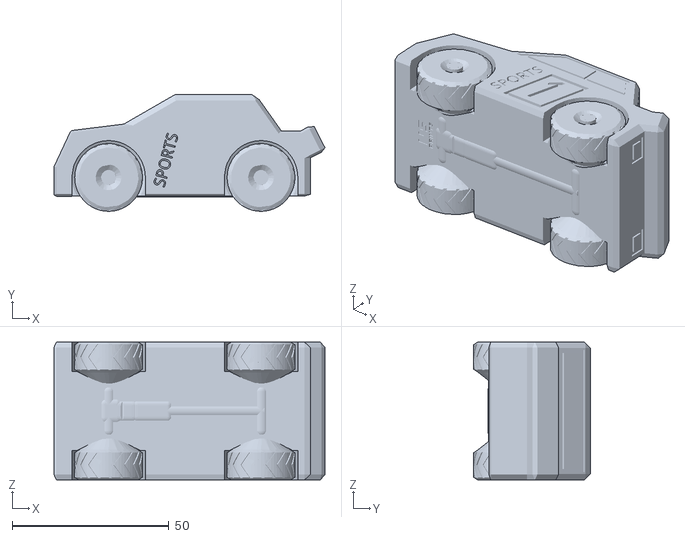
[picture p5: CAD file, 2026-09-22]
data/racecar.stl
86.4 x 37.2 x 44.0

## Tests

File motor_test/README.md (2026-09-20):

# Superseded

This sketch drives **RAMPS 1.4 pin numbers** (X = D54/D55/D38) on a GT2560,
whose X driver is on D25/D23/D27. It toggles pins that are not connected to
anything, so the motors never move and nothing reports an error.

Use `firmware/hwtest/` instead — same idea, correct pin map, plus endstop
readout, a hot wire output with a dead-man timer, and a serial console.

    make hwtest-flash
    make monitor

If you specifically want a plain Arduino IDE `.ino` (no PlatformIO) with the
correct GT2560 pins and a simple X/Y/Z/U console, use
**[`../gt2560_motortest/`](../gt2560_motortest/)**.

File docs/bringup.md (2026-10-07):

# Bring-up checklist

Work down the list. Each step either passes or tells you exactly which wire to
look at. Do not skip ahead: the point of the order is that a failure at step *n*
can only have been caused by something in step *n*.

Before anything else: **fit a fan blowing on the board.** Four energised
A4988s plus the wire MOSFET is more heat than a GT2560 shrugs off, and `$1=255`
in the shipped settings keeps the motors powered continuously so the wire does
not sag while hot.

---

## 1. Toolchain

```bash
make deps          # pip install -e host, pytest
make test          # 77 offline tests, no hardware needed
```

`make test` also cross-checks the two firmwares' pin maps against each other.
If it fails, fix that before flashing anything.

## 2. Firmware: grbl, und nur grbl

Auf dem Board läuft **grbl-Mega-5X**, dauerhaft. Es gibt keinen Grund, die
Firmware zu wechseln: Jog je Achse, alle vier zugleich, Draht-PWM und der
Endschalter-Zustand (`Pn:` im Statusreport, in der GUI oben rechts) sind
alle in grbl.

`firmware/hwtest/` bleibt als Notnagel für den Fall, dass ein Board
*überhaupt kein* Lebenszeichen gibt — bit-gebangte Pins ohne Planer, um
Pinbelegung und Treiber zu isolieren. Für diese Maschine ist das erledigt;
im normalen Betrieb nicht flashen (`foamcut hwtest`/`bounce` brauchen es).

## 3. Flash grbl

Einmalig, und nach jedem Firmware-Update:

```bash
make grbl-flash
foamcut probe                  # muss "Grbl 1.2i" melden
foamcut settings apply config/grbl_settings_foamcut.txt
```

## 4. Maschine vermessen: `foamcut setup`

Ohne Endschalter kann grbl weder referenzieren noch den Verfahrweg kennen.
`foamcut setup` macht beides von Hand und speichert das Ergebnis in
`config/machine.json` und in grbls Settings. Fünf Phasen, jede auch einzeln
(`foamcut setup --phases scale`):

| Phase | was passiert | schreibt |
|---|---|---|
| `mapping` | jede grbl-Achse fährt 5 mm, du sagst, was sich bewegt hat. Stimmt die Steckplatz-Belegung nicht, sagt es dir, welche Stecker zu tauschen sind, und bricht ab | — |
| `scale` | jede Achse fährt 20 mm, du misst nach | `$100..$103` |
| `direction` | jede Achse fährt +20 mm, du sagst ob "vorne" bzw. "oben". Falsch → Bit in `$3`, nicht umverdrahten | `$3` |
| `reference` | Tastatur-Jog in die Referenzecke (X, U hinten; Y, V unten), Enter → Arbeitsnull | `G10 L20 P1` |
| `travel` | jede Achse per Tastatur bis kurz vors andere Ende, Enter → Verfahrweg | `$130..$133`, `machine.json` |

Tastatur im Jog: `a/d` X, `s/w` Y, `j/l` U, `k/i` V, `1`..`4` Schrittweite
0.1 / 1 / 10 / 50 mm, Enter fertig, `q` Abbruch.

**Oder alles mit der Maus:** `foamcut gui` (Qt). Seiten: **Maschine**
(Verbindung, Jog-Pads beider Türme, Referenz, Verfahrweg, Endschalter,
Heizdraht und Schnittwerte; hier stehen auch Turmabstand und der Turm mit
dem festen Draht – sie gelten für alle Entwürfe), **Flügel** (Schritte links, Zeichnung rechts live, Warnungen
inline, letzte Werte gemerkt; als Profil geht ein Dateiname aus `airfoil/`,
eine vierstellige **NACA-Nummer** (`2412`, `naca2412`) oder **die drei Zahlen
selbst** – `2 40 12` = Wölbung %, Wölbungsrücklage % der Tiefe, Dicke %; damit
auch Zwischenwerte wie `2.5 40 11.5`, die keine Nummer trifft. Die Software
rechnet das Profil daraus (Hinterkante geschlossen); Schritt *Block* nennt Mindestblock und
Tischhöhe/-ausdehnung; Schritt *Rippen* schaltet zwischen **ganzes Teil**
(der Flügel am Stück, Wurzel- und Endprofil an je einem Turm) und **Rippen**:
dann entsteht ein Programm je Rippe, gleichmäßig über die Panellänge verteilt,
jede aus einem eigenen Stück Styropor – vor jeder sagt die Programmseite, wie groß
es sein muss, und lädt die nächste erst auf Knopfdruck. Beide Türme fahren dabei
gleich (die Rippe ist dünn, ihre Neigung bei Zuspitzung wird vernachlässigt),
aber jede Rippe bekommt Tiefe und Schränkung ihrer Stelle; Holmnuten behalten
ihr Maß, eine Leiste wird ja nicht dünner. Schritt *Holme* hat sechs Zeilen für Nuten und
Löcher, je eine Leiste, jede mit einem Häkchen ein- und ausschaltbar (der Wert
bleibt stehen; in der Datei steht dann „aus“ davor). Format für Flügel **und**
Formen gleich: **`<Winkel> [innen] <b>x<h>`** – Winkel in Grad um die Mitte des
Querschnitts, im Uhrzeigersinn von oben (0 oben, 90 vorn/Nase, 180 unten, 270
hinten). Die Nut sitzt dort, wo dieser Strahl die Kontur verlässt, und steht
senkrecht auf ihr, damit die Leiste flach darin liegt; `innen` macht daraus ein
geschlossenes Loch 1 mm unter der Haut (nur im Körper, der Draht käme nicht
hinein). Ist das Teil länger als der Turmabstand, ist das **kein Fehler mehr**,
sondern ein Hinweis: am Stück lässt es sich nicht schneiden, als Körper (STL)
und für Rippen aus Scheiben ist es weiter brauchbar.
Ältere Flügeldateien mit `30% oben 6x4` (Lage ab Nasenleiste) werden
weiter gelesen – das ist der Weg, wenn es auf eine bestimmte Profiltiefe
ankommt. „STL speichern…“ gibt den Flügel als
Körper aus, mit Nuten und Löchern: daraus lassen sich später auf der Seite
*Scheiben* Rippen schneiden und mit Holzleisten zu einem größeren Flügel
zusammensetzen. Innenlöcher schneidet der Draht am Flügel selbst nicht – er
käme nicht hinein, ohne ihn aufzuschlitzen), **Formen** (freie Querschnitte je Seite, Scheibe
oder Ring – Rumpfsegmente; Schritt *Holme* mit demselben Format wie beim
Flügel, „STL speichern…“ gibt auch hier den Körper aus), **Kontur** (SVG-Zeichnung aus Inkscape als
Parallelschnitt X=U/Y=V: Buchstaben, Silhouetten; Löcher über einen Schlitz
nach hinten, mehrere Teile nacheinander, Text vorher in Pfade umwandeln),
**Scheiben** (STL-Körper in Scheiben einer Dicke; Scheiben „2,3,4“, „1-5“, „$“ für die
letzte, „*3“ für jede dritte (von der ersten an) oder „alle“ – gemischt, also
etwa „1,*3,$“ für die erste, jede dritte und die letzte – werden nebeneinander
auf einer Schaumplatte der Scheibendicke
angeordnet (Platte Länge/Höhe, sonst Verfahrweg): Umrisse statt Rechtecke,
Vierteldrehungen erlaubt, kleinstes umschließendes Rechteck, Scheiben
2 × Schnittbreite + 0,5 mm auseinander; die Teile werden als **Kette**
geschnitten: ein Einlauf, dann je Teil ein Bogen, über den Steg zum Nachbarn
(entlang der Verbindung der Mittelpunkte), am Ende umkehren und auf dem
Rückweg den jeweils anderen Bogen – die Kanäle dazwischen werden zweimal
befahren, nicht neu geschnitten. Die Kette läuft von oben nach unten, also
kommt beim Rückweg das unterste Teil zuerst frei und der Draht fährt von ihm
weg. Wo ein Steg ein drittes Teil träfe (oder ein Haltesteg gesetzt ist),
fährt die Software wie bisher Teil für Teil von hinten an; Scheibenliste mit Enter bestätigen; der Draht
fährt zwischen ihnen um die schon geschnittenen herum; passen nicht alle, gibt es **ein
Programm je Platte** (`…_platte1.nc`, `_platte2.nc`): die Programmseite zeigt
nach dem Ende von Platte 1, welche Platte einzulegen ist, und lädt Platte 2
erst über „Nächste Platte laden…“ – dann wie immer Start; **verlaufend** ist der Normalfall: beide Türme
fahren unabhängig, die Scheibe bekommt ihre beiden echten Schnittflächen und
damit den Winkel eines konischen Rumpfs (Sehnenfehler je Scheibe im Ergebnis);
zerfällt ein Schnitt in mehrere Umrisse, wird jeder mit seinem Gegenstück
gepaart. **Prismatisch** (`verlaufend = nein`) ist der Rückfall, wenn die
beiden Flächen nicht zusammenpassen. Die Plattenlage entlang des Drahts kommt
von der Software (mittig zwischen den Türmen, so teilt sich der Schrägversatz
gleichmäßig auf beide Schlitten) oder aus dem Feld *Seite A ab Turm*;
Holmnut von oben/unten in Körperkoordinaten, also in jeder Scheibe an
derselben Stelle – Rümpfe und große Flügel aus Schaumscheiben auf Holmen;
Reiter „Objekt“ zeigt Zeichnung bzw. drehbaren Körper mit markierter Scheibe),
**Programm & Sim** (laden/umsetzen,
Turtle-Simulation beider Schlittenwege, Start/Pause/Stop). Beim Verbinden
gleicht die GUI alle grbl-Settings mit `config/` ab.

**Schachteln (mehrere Teile in einem Block):** Seite „Schachteln“ oder
`foamcut nest LISTE.batch`. Gespeicherte `.wing`/`.shape`/`.contour`/`.slices` in die Liste laden,
Reihenfolge = Schnittreihenfolge von oben nach unten (das letzte Teil liegt
auf dem Tisch). Die Teile werden in Y gestapelt, Abstand „gap“ dazwischen –
geprüft über die ganze Blockbreite, weil der Draht bei kürzeren Teilen hinter
deren Ende weiterschneidet. Haken „Paar“ an einem Flügel: zusätzlich das
Spiegelbild (in Spannrichtung umgedreht, Wurzel am Gewichtsturm) darüber,
dünnes Ende über dickem. Zwischen den Teilen fährt der Draht 5 mm hinter der
Blockrückseite (kein Schaum) senkrecht zum nächsten Einlauf, nie über
Geschnittenes. Ein Programm, ein `M3`. Die Liste lässt sich als `.batch`
speichern (`config/beispiel.batch`).

**Lauf live:** Während ein Programm läuft, zeigen die beiden Ansichten auf
„Programm & Sim“ die echte Position (rotes Fadenkreuz mit Koordinaten, aus den
Statusmeldungen 5×/s) und die tatsächlich gefahrene Spur (rosé); die geplante
Bahn füllt sich in Farbe, sobald grbl die Zeilen angenommen hat (bis ~16
Bewegungen voraus), der Rest liegt blass darunter. Die Spur bleibt nach dem
Ende stehen, bis das nächste Programm startet.

**Freischnitt (Maschine-Seite):** an eine Stelle joggen, Länge und Vorschub
eintippen, **vor / zurück / hoch / runter** (oder Winkel + „schräg“) — ein
gerader Schnitt ab der aktuellen Position, beide Türme gleich, optional „und
zurück“. Läuft als Programm (Pause/Stopp/Fortschritt), die Bereichsprüfung
rechnet ab der aktuellen Position. **Turm 2 versetzt U/V:** Turm 2 fährt
vorher (Draht kalt) um U nach vorn bzw. V nach oben, der Draht steht schräg
und der Schnitt wird eine schräge Ebene — U mit ↑/↓ ergibt eine Pfeilungs-
fläche (Winkel = atan U/Turmabstand), V mit →/← eine über die Spannweite
geneigte Fläche. Am Ende stellt sich der Draht wieder gerade. Eine V-Form-
Wurzelfläche (aus der Senkrechten gekippt) kann der Draht nicht.

**Kontrollschnitt nach Skalen-Änderung:** 100-mm-Freischnitt „und zurück“ in
eine Platte, an beiden Türmen nachmessen — beide Enden gleich lang, sonst
stimmen Schritte/mm (`$100..$103`) nicht. Gespiegelt und normal ergeben
denselben Umriss (nur kopfüber); Abweichungen zwischen beiden kommen von der
Maschine oder der Messstelle (ein Trapez ist alle 10 cm ~1 cm anders breit).

**Block und Tisch:** der Block liegt auf dem Tisch, seine Unterkante *ist*
`table_y`; nur waagerecht (Länge, Spannbereich) sind Block und Tisch getrennt.
Alte `.wing`/`.shape` mit `block_y` werden umgerechnet.

**U läuft mit 3200 Schritten/mm** (Treiber im Z-Slot steht auf 1/32,
Lineal-Test 16.09.): so steht es jetzt in `machine.json`; ein Rechteckflügel
wurde vorher als Trapez geschnitten, weil U nur halb so weit fuhr. Jumper auf
1/16 umstecken und `foamcut setup --phases scale --jog-mm 50 --axes U` gäbe U
wieder 750 mm/min statt 375.

**Nach jedem Einschalten:** `foamcut ref` oder in der GUI „Referenz hier setzen". grbl weiß nach einem Neustart nicht
mehr, wo es steht — die Referenzecke einmal anfahren, Enter, fertig. Danach
prüft `foamcut run` jedes Programm gegen den gespeicherten Verfahrweg und lehnt ab,
was darüber hinausfährt.

## 5. Sync und Schnitt

### Four axis synchronisation

```bash
foamcut check gcode/05_sync_diagonal.nc     # offline first
foamcut run   gcode/05_sync_diagonal.nc
```

Every move changes all four axes by different amounts. Both towers must start
and stop together. If one arrives late, it is losing steps: lower `$110..$113`
or raise the driver current.

### The wire

With the wire strung and tensioned but nothing to cut:

```bash
foamcut run gcode/03_wire_ramp.nc
```

Find the lowest `S` value that melts foam without the wire glowing red. With
`$30=255` the `S` value *is* the PWM count, so `S128` is 50 % duty.

### First cut

```bash
foamcut run gcode/01_square.nc      # prismatic block, both towers identical
foamcut run gcode/02_taper.nc       # tapered block, towers travel different distances
```

The taper is the test a 3 axis controller cannot pass. Measure both ends: left
should be 60 mm, right 30 mm, minus the kerf. The cut settings - feed,
wire power, warm-up and kerf (Schnittbreite) - are entered once on the
machine page (or `foamcut machine set --feed 300 --wire 180 --warmup 3
--kerf 1.2`); they live in `machine.json` and apply to wings, shapes, batches
and the free cut alike. `feed`, `wire`, `warmup`, `kerf` lines in old
`.wing`/`.shape` files are ignored.

Then set feed and wire power together — see "Feed rate and temperature" in the
[reference project's README](https://github.com/rahulsarchive/4AxisFoamCutter).
Faster feed needs a hotter wire; too slow at any temperature widens the kerf
because the foam keeps melting while the wire dawdles.

---

## Endschalter und Referenzfahrt

Vier Öffner (NC, zwischen S und GND), alle am negativen Ende (X/U hinten,
Y/V unten), verdrahtet am 18.09.2026: **X an X_MIN, Y an X_MAX, U an Y_MIN,
V an Y_MAX** — die GT2560 hat keinen vierten Endschalter-Stecker, die X/Y-
Paare decken alle vier ab (gt2560_pinout.md). Die Öffner-Umkehr ist in der
Firmware fest (`INVERT_MIN_LIMIT_PIN_MASK`); `$5` bleibt 0, weil grbl-Mega-5X
bei `$5=1` MIN- und MAX-Eingang verknüpft und die leeren MAX-Eingänge dann wie
gedrückt aussehen (ALARM:8 beim Homing).

Gelernt am 19.09.2026: `machine.json` hatte `invert_dir` für Y/V verloren,
der Abgleich schrieb `$3=0` — +Y fuhr nach unten, das Homing nach oben,
Kollision. `$3=10` ist Pflicht (Y und V invertiert); `foamcut settings dump`
zeigt es, der Abgleich beim Verbinden stellt es aus `machine.json` wieder her.

Dass vier Schalter nicht auf den Zehntelmillimeter fluchten und der Draht bei
"beide Türme am Schalter" nicht waagerecht hängt, ist eingeplant: die
Schalter liefern den **Maschinen-Nullpunkt**, der **Arbeitsnullpunkt** liegt
pro Achse um einen Versatz in + davon (G54). Alle Programme laufen im
Arbeitskoordinatensystem.

GUI → **Endschalter…**:

1. Schalterart (NO/NC), Pull-off, Geschwindigkeiten. Haken "Endschalter
   verwenden". **Schalterzustand lesen** und jeden Schalter von Hand drücken:
   es muss genau die richtige Achse erscheinen — das prüft Verdrahtung und
   NO/NC, bevor sich etwas bewegt.
2. **Referenzfahrt jetzt ($H)** — gedrückte Schalter werden erst 5 mm
   freigefahren, dann fahren alle vier Achsen langsam auf ihre Schalter,
   Pull-off 2 mm (bei 0 ist kein Schalter ausgelöst). Beim ersten Mal die
   Hand am Netzschalter: fährt eine Achse *vom* Schalter weg, stimmt ihre
   Richtung nicht (`$3`-Bit der Achse), grbl bricht nach 1,5× Länge ab.
   Beim Verbinden läuft die Referenzfahrt automatisch (`homing.auto`).
3. Versatz: alle Achsen im Hauptfenster joggen, bis sie stehen, wo Null sein
   soll (Draht waagerecht!), dann **Referenz hier setzen** — das speichert den
   Versatz ab Schalter für alle vier Achsen und setzt G54. (Im Dialog geht es
   auch je Achse mit **= aktuelle Position**.)
4. Je Achse **Länge ab Schalter** eintippen (nutzbarer Weg, nicht anfahren;
   die Suchfahrt läuft bis 1,5× dieser Länge, also nicht zu klein).
5. **Speichern & aufs Board** — `machine.json` + `$5 $20 $22 $23 $24 $25 $27
   $130..$133` + G54. Bleibt bis zur nächsten Kalibrierung.

Ab dann nach jedem Einschalten: grbl startet im Alarm, die GUI fährt die
Referenz automatisch und landet auf dem gespeicherten Arbeitsnull. Kein `$X`
mehr, kein Ecke anfahren. Softlimits sind aktiv: grbl lehnt Fahrten außerhalb
der Länge ab (error 15), zusätzlich zur Host-Prüfung in `foamcut check`/`run`.
Spricht während einer Fahrt trotzdem ein Schalter an, hält die GUI an,
setzt zurück und meldet es — dann stimmen Nullpunkt oder Länge nicht.

Achtung Kommandozeile: jedes Öffnen/Schließen des Ports setzt das Board zurück
(DTR), danach ist die Position wieder unbekannt. `foamcut home` allein bringt
also nichts Dauerhaftes; die GUI hält die Verbindung.

Kommandozeile: `foamcut homing set --enable --nc --offset V=1.5 --length X=160
Y=105 U=160 V=105`, `foamcut homing show`, `foamcut home`.

Die Phasen `reference` und `travel` von `foamcut setup` sind nur für Maschinen
ohne Schalter.

## Halber Weg auf einer Achse: Schritte/mm

Fährt eine Achse **bei jeder Geschwindigkeit gleich falsch** (z. B. nur den
halben Weg), stimmen die Schritte/mm nicht — fast immer, weil der Treiber in
einem anderen Mikroschritt läuft als angenommen (U war so: 1600 → 3200; Y/V
am 2026-09-23: 8704 → 17408). Sind die Fehler dagegen nur bei hohem Vorschub
da, verliert die Achse Schritte, dann ist die Schrittrate zu hoch.

```bash
foamcut machine set --steps Y=17408 --steps V=17408   # neu = alt * befohlen / gemessen
```

Der Wert landet in `machine.json` und beim nächsten Verbinden auf dem Board.
Achtung: doppelte Schritte/mm halbieren den möglichen Vorschub (20 kHz
Schrittbudget, `MAX_STEP_HZ`) — `machine set` sagt, worauf es kappt. Wer die
Geschwindigkeit behalten will, stellt stattdessen den Treiber zurück auf den
angenommenen Mikroschritt (Jumper MS1/MS2 unter dem Treiber) und lässt den
alten Wert stehen.

## The feed rate surprise

This build sets `N_AXIS_LINEAR = 4`, so grbl applies the feed rate to the
euclidean norm over **all four** axes. A move where both towers travel 100 mm
has a path length of 141 mm, so at `F300` each tower actually crosses the foam
at 212 mm/min, not 300. `foamcut check` reports this as a note on any file where it
happens. Account for it when you translate a cutting speed into an `F` word.

---

## Motor brummt, dreht aber nicht

Zuerst ausschliessen, dass es die Schrittfrequenz ist - der hwtest faehrt ohne
Rampe los, und ein knapp eingestellter Treiber verschluckt sich daran:

    foamcut bounce X --steps 3200 --step-us 2000 --no-guard   # 4,7 U/min

Dreht er langsam sauber, war es zu schnell: Vref hoch, dann wieder schneller.
Brummt er auch hier, ist es die Verdrahtung oder der Strom. Dass er ueberhaupt
brummt, ist dabei eine gute Nachricht - Enable, Step und Dir kommen am Treiber
an, die Pinbelegung stimmt also.

**Vref messen.** Multimeter an den Trimmer des A4988 gegen GND, Board bestromt,
Motor angeschlossen. Es gilt `Vref = I_soll * 8 * R_sense`; bei den ueblichen
0,1 Ohm sind das fuer 1,2 A rund 0,96 V. Nahe null heisst: der Motor bekommt
keinen Strom und brummt nur.

**Spulenpaare pruefen.** Vier Adern, zwei Spulen. Multimeter auf Ohm: genau
zwei Adernpaare haben ein paar Ohm zueinander, zwischen den Paaren misst du
unendlich. Diese Paare muessen im Stecker *nebeneinander* liegen, also Pin 1+2
eine Spule und Pin 3+4 die andere. Verschraenkt man sie (1+3 / 2+4), brummt der
Motor und dreht nicht - das ist der mit Abstand haeufigste Fall.

Ohne Multimeter: zwei Adern verdrillen und die Welle von Hand drehen. Wird sie
spuerbar schwergaengig, gehoeren die beiden zu einer Spule.

**Im Zeitlupentempo zusehen.** 160 Schritte bei 60 ms je Halbperiode sind
10 Vollschritte in gut 20 Sekunden - da siehst du jedem Schritt einzeln zu:

    foamcut bounce X --steps 160 --step-us 60000 --no-guard

Richtig verdrahtet rueckt die Welle sichtbar Schritt fuer Schritt weiter.
Verschraenkt pendelt sie nur hin und her.

---

## Board meldet sich nicht

Symptome, die zusammen auftreten und alle auf die *gleiche* Ursache zeigen:

* `ls /dev/ttyUSB*` zeigt den Port mal, mal nicht, und die Nummer wechselt
  (ttyUSB0 → ttyUSB1 → weg). In `lsusb` steigt die Device-Nummer bei jedem Mal.
* Das Board sendet nach einem DTR-Reset auf **keiner** Baudrate etwas
  (250000 / 115200 / 57600 alle 0 Bytes).
* `avrdude -c wiring` läuft in lauter `stk500v2_recv(): timeout`,
  `avrdude -c arduino` meldet `not in sync: resp=0x00`.

Das heißt: der CH340 (USB-Seriell-Wandler) bekommt Strom aus dem USB und meldet
sich, der ATmega2560 dahinter läuft nicht. Die Reihenfolge zum Prüfen:

1. **Netzteil an, Board-LEDs an?** Ohne Logikversorgung läuft nur der Wandler.
2. **USB-Kabel tauschen.** Ein Ladekabel ohne Datenadern oder ein zu langes /
   schlechtes Kabel lässt den CH340 genau so flattern. Direkt am Rechner
   anstecken, nicht über einen Hub.
3. **Alles abklemmen** — Motoren, Endschalter, Heizdraht — und nur USB plus
   Netzteil. Ein Kurzschluss an einem Treiber zieht die 5 V herunter und das
   Board bootet in einer Schleife.
4. **Reset-Taster** auf dem Board drücken und den Flash-Befehl im selben Moment
   starten, falls der Auto-Reset über DTR nicht verdrahtet ist.

Erst wenn `foamcut probe` eine Firmware-Zeile ausgibt, weitermachen.

    foamcut probe        # sagt, welcher Port da ist und welche Firmware antwortet

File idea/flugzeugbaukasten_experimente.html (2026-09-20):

# Flugzeugbaukasten Experimente

Quelle: https://chatgpt.com/g/g-p-69c3ebacd09081919d16054124f6bb4c-flugzeugbaukasten/c/69c3ecfe-2ea4-8332-85e2-9e45e01aa09f

#### Valentin

Projekt JuFo 17jA junge. Ziel "Baukasten" für flugzeugmodelle. Verschiedene Flügel(segmente), verschiebbare positionen, Verschiedene Flächenund formen von leitwerken, evtl verschiedene oberflächen, damit die jugentlichen schnell erkunden können was fliegt und was nicht. Gräße bis max 1m spannweite. Welche experimente kann man machen? Projektzeit ca 1J, ca 2xstunden die Woche

#### ChatGPT

Ah, das klingt nach einem richtig spannenden „Mini-Flugzeug-Labor“ für Jugendliche! Mit so einem Baukasten könnt ihr eine Menge Experimente machen, die sowohl aerodynamisches Verständnis als auch praktisches Basteln fördern. Ich fasse das mal strukturiert zusammen:

## 1. Flugzeugbau-Baukasten-Grundideen

Variablen, die ihr testen könnt:

- Flügel:
  - Verschiedene Spannweiten (z. B. 40 cm – 1 m)
  - Verschiedene Flügeltiefen (Breite von Wurzel zu Spitze)
  - Formvariationen: rechteckig, trapezförmig, elliptisch
  - Profilvariationen: dünn, dick, leicht gewölbt
  - Flügelanstellwinkel verändern
- Leitwerke:
  - Höhenleitwerk vorne/hinten (Canard vs. klassisch)
  - Verschiedene Flächen (klein, groß)
  - Symmetrische vs. gewölbte Profile
  - Höhenleitwerk- und Seitenleitwerk-Anstellwinkel variieren
- Rumpf & Schwerpunkt:
  - Verschiebbare Akkus oder Ballast zur Schwerpunktverlagerung
  - Länge und Form des Rumpfes verändern
- Oberflächen:
  - Glatt vs. rauh
  - Unterschiedliche Materialien (Schaum, Balsa, Papier)
  - Leichte Rippenstrukturen vs. glatte Fläche

## 2. Mögliche Experimente

Hier ein paar Ideen, die Jugendliche in ~2 Stunden pro Woche umsetzen können:

### A) Grundlagen der Aerodynamik

1. Flügelprofil vs. Auftrieb:
  - Testet Flügel verschiedener Profile bei gleichem Anstellwinkel und Flügelfläche.
  - Beobachtet Stabilität, Gleitwinkel, Sinkgeschwindigkeit.
2. Flügelspannweite vs. Effizienz:
  - Kürzere vs. längere Spannweite bei gleicher Fläche
  - Erkennt: kürzere Flügel → schnellerer Sinkflug, längere → besserer Gleitwinkel
3. Anstellwinkel ändern:
  - Welcher Winkel gibt maximale Flugweite?
  - Bei zu großem Winkel: Strömungsabriss sichtbar

### B) Flugstabilität

1. Leitwerkposition (Canard vs. klassisch):
  - Verschiebbare Höhenleitwerke → Wirkung auf Pitch-Stabilität
  - Welches Layout ist „selbststabiler“?
2. Schwerpunktverlagerung:
  - Mit verschiebbarem Gewicht
  - Erkenntnis: zu weit hinten → instabil, zu weit vorne → schwer zu starten
3. Seitenleitwerk-Formen:
  - Unterschiedliche Größe oder Höhe
  - Wirkung auf Gierstabilität beobachten

### C) Aerodynamische Effizienz

1. Flächenform:
  - Rechteck, Trapez, Ellipse → Wirkung auf Gleitwinkel
  - Erkennt: elliptische Flügel oft effizienter, trapezförmig einfacher zu bauen
2. Oberflächen:
  - Rauh vs. glatt → Einfluss auf Luftwiderstand
  - Leicht strukturierte Flügel vs. glatte Folie

### D) Kreative Herausforderungen

1. Mini-Wettbewerbe:
  - Wer baut das Flugzeug, das am weitesten gleitet?
  - Wer kann längste stabile Flugbahn erreichen?
2. “Bau den verrücktesten Flieger”
  - Ungewöhnliche Flügel- oder Leitwerkskombinationen testen
  - Spaßfaktor + Erkenntnisse, warum manche Designs scheitern
3. Materialexperimente:
  - Balsa, Styropor, Papier → Unterschiede im Gewicht und Verhalten

## 3. Projektplanung (~1 Jahr, 2 Std/Woche)

Phase 1 – Grundlagen & Baukasten (2–3 Monate)

- Bau eines Grundmodells, einfache Flügel/Leitwerke
- Einführung: Schwerpunkt, Anstellwinkel, Flugtests

Phase 2 – Systematisches Experimentieren (4–6 Monate)

- Variationen an Flügeln, Leitwerken, Schwerpunkt
- Messung: Flugweite, Sinkgeschwindigkeit, Stabilität

Phase 3 – Fortgeschrittene Experimente (3–4 Monate)

- Oberflächenmaterialien
- Kombination verschiedener Segmente
- Wettbewerb: „bestes Gleitflugzeug“

Phase 4 – Abschluss & Präsentation (1–2 Monate)

- Ergebnisse dokumentieren, Diagramme, Videos
- Erkenntnisse aus Baukasten teilen

Wenn du willst, kann ich dir als Nächstes einen konkreten Baukasten-Entwurf für ~1 m Spannweite machen, bei dem man Flügel, Leitwerke und Schwerpunkt modular variieren kann, inklusive Materialliste und Tauschbarkeit für die Experimente.

Willst du, dass ich das mache?

#### ChatGPT

Ja, absolut – genau das ist ein klassischer und sehr lehrreicher Ansatz in der Aerodynamik: gleiche Fläche, unterschiedliche Form. Damit kann man den Einfluss der Geometrie isoliert vom Einfluss der Größe untersuchen.

Hier ein paar Punkte dazu:

### 1. Warum gleiche Fläche, unterschiedliche Form sinnvoll ist

- Auftrieb: Grundsätzlich hängt der Auftrieb bei gleichem Anstellwinkel und gleicher Fläche ziemlich stark von der Fläche selbst ab.
- Indirekte Effekte der Form:
  - Flügelspanne vs. Flügeltiefe → beeinflusst Induzierten Widerstand (Wirkung auf Gleitwinkel, Effizienz)
  - Trapez vs. Rechteck vs. Ellipse: Elliptisch verteilt die Auftriebskraft gleichmäßiger → weniger Wirbel am Flügelende → besserer Gleitwinkel
  - Längere, schmalere Flügel: Bessere Effizienz, stabiler gegen Seitwärtsdrall
  - Kürzere, breitere Flügel: Einfacher zu bauen, evtl. mehr induzierter Widerstand
- Wirkung auf Stabilität:
  - Formänderungen verändern den aerodynamischen Schwerpunkt leicht
  - Unterschiedliche Widerstandsverteilung → beeinflusst Pitch- und Rollverhalten

### 2. Typische Vergleichsexperimente

1. Elliptisch vs. rechteckig:
  - Beide Flügel haben gleiche Fläche, aber unterschiedliche Spannweite und Flügeltiefe
  - Beobachten: Flugweite, Sinkgeschwindigkeit, Stabilität
2. Trapez vs. rechteckig:
  - Gleiche Fläche, unterschiedliche Enden → zeigt Einfluss der Flügelspitzen
  - Erkennt: Trapezform einfacher zu bauen, Ellipse effizienter
3. Canard- oder klassische Leitwerksvariationen mit gleicher Fläche:
  - Gleiche Gesamtfläche, aber verlagert → Stabilität vs. Gleitflug

### 3. Praktischer Tipp

- Beim Baukasten: immer die Fläche messen, bevor ihr Formen vergleicht. Dann könnt ihr sauber sagen: „Wir vergleichen die Wirkung der Form, nicht der Größe.“
- Nutzt einheitliche Materialien, sonst verfälscht Gewicht den Vergleich.

Wenn du willst, kann ich eine Liste von konkreten Flügelformen für den Baukasten machen, bei denen jede die gleiche Fläche hat, aber spannend unterschiedliche Form und Spannweite – perfekt für die Experimente.

Willst du, dass ich das zusammenstelle?

#### Valentin

gibt es flache, leichte verbindungselemente, die ich z.B. als Verbindungselementen zwischen Flügelsegmenten nutzen kann? sie sollen an den seiten (letzten flügelrippen) der flugelsegmente fest geklebt sein und andede segmente ermöglichen zu verbunden. sollen selbst sehr flach sein. Verbindung soll wieder löslich sein. so wie lego nur leichter oder mehrfach läsliches klebstreigen?

#### ChatGPT

Ah, jetzt wird’s richtig praktisch – du suchst quasi flache, wieder lösbare Verbindungselemente für Modellflugzeug-Flügelsegmente, die leicht sind, nicht dick auftragen und trotzdem stabil genug für Flugtests. Ich gebe dir ein paar bewährte Lösungen und Ideen:

## 1. Mechanische Verbindung, flach & leicht

### A) Magnetverbindungen

- Neodym-Magnete (flach, wenige mm dick, rund oder quadratisch)
- Vorteile:
  - Extrem flach → kaum Aufbauhöhe
  - Schnell zu trennen und wieder verbinden
  - Gewicht sehr gering
- Tipps:
  - Magnete auf den letzten Rippen aufkleben (z. B. Epoxidharz oder Sek. Kleber)
  - Gegenstücke passend im anderen Segment
  - Aufpassen: Polung muss korrekt sein, sonst stoßen sie sich ab

### B) Flache Steckverbindungen

- Kunststoff-/Balsa-Stifte oder dünne Lamellen
- Ähnlich wie Lego, aber leichter:
  - z. B. 2–3 mm runde Hartholz- oder Kunststoffstäbe
  - In Rippen eingelassen → Segment kann aufgesteckt werden
- Vorteile: leicht, wieder lösbar
- Nachteile: braucht präzises Bohren / Einpassen

### C) Klettband / Hook-and-Loop

- Dünnes Nylon-Klettband (z. B. 2–3 mm dick)
- Vorteile: wieder lösbar, sehr leicht
- Nachteile: hält nur, wenn die Verbindung nicht stark belastet wird (also eher für kleine Segmente oder Modellgewicht < 200 g)

## 2. Klebe-basierte, wieder lösbare Varianten

### A) Wieder löslicher Klebestreifen

- Repositionierbarer Kleber / Removable Glue Dots
  - Dünn → nur wenige Zehntel mm
  - Leicht zu lösen, mehrmals verwendbar
- Praktisch für: Testflüge, bei denen Flügelsegmente oft gewechselt werden

### B) Low-tack Doppelseitiges Klebeband

- z. B. 3M „Command Strips“-Mini, dünn geschnitten
- Hält leicht, abziehbar, sehr flach

## 3. Kombi-Ideen

- Magnet + dünner Klebestreifen:
  - Magnete für Fixierung, Kleber für Ausrichtung
- Steckstift + Klett:
  - Stifte geben Führung, Klett hält sanft
- Magnet + Low-tack Kleber:
  - Positionieren → magnetisch fixieren, bei Bedarf ziehen

### 4. Material-Tipps

- Gewicht sparen:
  - Magnete: max 3×1 mm für 1 m Spannweite Segmente
  - Kunststoffstifte: Hohl oder aus Balsaholz
  - Klebeband: dünn, Nylon oder Papierbasis
- Flach bleiben:
  - Alle Elemente maximal 1–2 mm aufbauend
  - Auf letzten Rippen oder Rumpfanschluss verkleben

💡 Praxis-Tipp: Für den JuFo-Baukasten würde ich Magnetleisten oder kleine runde Neodym-Magnete empfehlen, weil sie stabil, leicht, flach und mehrfach lösbar sind. Wenn ihr die Segmente oft tauscht, sind Magnete auf Dauer einfacher als Klebstoff oder Steckstifte.

Wenn du willst, kann ich dir ein paar konkrete Mini-Magnet-Kombinationen zusammenstellen, die für 1 m Spannweite Flügel optimal sind, inklusive Klebe- und Anordnungsvorschläge.

Willst du, dass ich das mache?

#### Valentin

Stimmt, stifte zur positionierung und montagestreifen zwischen den Segmenten!!!

#### ChatGPT

Genau! 🎯 Das ist eine superpraktische Kombination:

- Stifte (Holz, Kunststoff oder Balsa) übernehmen die präzise Positionierung der Segmente. Sie sorgen dafür, dass die Flügelrippen oder Leitwerke exakt ausgerichtet bleiben – wie kleine Führungen.
- Dünne Montage- oder Klebestreifen zwischen den Segmenten sorgen für sanfte Fixierung und halten die Teile leicht zusammen, aber wieder lösbar.

So hast du:

1. Exakte Ausrichtung → Stifte verhindern Verdrehen oder Schräglage
2. Flache Verbindung → Streifen dünn genug, dass die Aerodynamik kaum leidet
3. Wieder lösbar → Segmente können für Experimente schnell getauscht werden

💡 Praktischer Tipp:

- Stifte leicht konisch oder minimal kleiner als Bohrung → einfach aufsteckbar, aber nicht zu locker
- Montageband oder dünner Kleber nur auf den Kontaktflächen → kein Aufbau über die Rippenkante hinaus
- Optional: Stifte und Streifen farblich markieren, damit Jugendliche schnell sehen, wie die Segmente zusammengehören

Wenn du willst, kann ich dir eine kleine Skizze für so eine Flügelverbindung machen, inkl. Positionierung der Stifte und Klebestreifen – quasi als Baukasten-Blueprint für die Jugendlichen.

Willst du, dass ich das zeichne?

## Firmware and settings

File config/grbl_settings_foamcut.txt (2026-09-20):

# grbl-Mega-5X settings for the GT2560 XYUV hot wire cutter.
#
# Apply with:   foamcut settings apply config/grbl_settings_foamcut.txt
# Read back:    foamcut settings dump
#
# Axis order is X Y U V -> $100..$103, $110..$113, $120..$123, $130..$133.
# Everything marked MACHINE must be measured on your machine; see
# docs/bringup.md step 5 (steps/mm calibration).

# --- stepper timing -------------------------------------------------------
$0=10        # step pulse, us (A4988/DRV8825 need >= 2 us; 10 is safe)
$1=25        # step idle delay, ms. All four axes are self-locking lead
             # screws, so the motors are released 25 ms after standstill:
             # zero hold current, no driver heat, no drift. (255 = never
             # release - only for belt axes, which this machine has none of.)
$2=0         # step port invert mask
$3=10        # direction invert: Y and V (bits 1 and 3). Measured: +Y/+V ran down.
$4=0         # invert stepper enable (0 is correct for A4988: EN is active low)
$5=0         # invert limit pins: 0 = NO switch to GND (internal pull-up),
             # 1 = NC switch. machine.json "homing.invert_switch" overrides.
$6=0         # invert probe pin

# --- reporting ------------------------------------------------------------
$10=3        # status report: machine position + buffer state
$11=0.010    # junction deviation, mm
$12=0.002    # arc tolerance, mm
$13=0        # report in mm

# --- limits and homing ----------------------------------------------------
# Base values for a machine WITHOUT switches. Once "homing.enabled" is true in
# config/machine.json (foamcut homing set --enable / GUI "Endschalter…"), the GUI
# and foamcut home push $5 $20 $22 $23 $24 $25 $27 $130..$133 from there instead.
$20=0        # soft limits: need homing, so off here; on with switches
$21=0        # hard limits off. Needs ENABLE_RAMPS_HW_LIMITS in config.h,
             # because no GT2560 endstop input has a pin change interrupt.
$22=0        # homing off without switches
$23=0        # homing direction: with switches 15 = all four seek toward the
             # negative end (X/U back, Y/V down)
$24=100.0    # homing feed, mm/min
$25=800.0    # homing seek, mm/min
$26=50       # homing debounce, ms
$27=3.0      # homing pull-off, mm

# --- hot wire (grbl calls it the spindle) --------------------------------
$30=255      # max "spindle" speed. The PWM is 8 bit, so S255 = 100 % duty and
             # an S value is directly the PWM count.
$31=0        # min
$32=0        # laser mode off. Setting $32=1 scales wire power with feed rate,
             # which reduces kerf in corners - try it once cutting works.

# --- steps per mm ---------------------------------------------------------
# Measured 2026-09-12:
#   horizontal NEMA17, T8x2:  20 mm at 2560 -> 32 mm      => 1600  (2.0 mm/rev)
#   vertical   NEMA14 screw:  20 mm at 2560 -> ~5.9 mm, then
#                             20 mm at 10240 -> 17 mm     => 8704  (0.37 mm/rev)
# TMC2208/2209 standalone, MS1+MS2 jumpered = 1/16, 3200 steps/rev.
# Directions: +X/+U = forward (origin at the back) as wired; +Y/+V = up needs $3=10.
$100=1600.0  # X  tower 1, horizontal
$101=8704.0  # Y  tower 1, vertical
$102=1600.0  # U  tower 2, horizontal
$103=8704.0  # V  tower 2, vertical

# --- max rate, mm/min -----------------------------------------------------
# The limit is grbl's stepper interrupt on the ATmega2560. Measured on this
# machine 2026-09-13: 24 kHz runs, 30 kHz (1125 mm/min on X) locks the MCU
# up mid-move - it stops answering until the port is reopened (DTR reset).
# Budget is 20 kHz (MAX_STEP_HZ in machine.py); the GUI derives these from
# steps/mm and clamps anything higher:
#   horizontal 20000 / 1600 = 12.5 mm/s = 750 mm/min
#   vertical   20000 / 8704 =  2.3 mm/s = 138 mm/min
# grbl scales any move down to respect these, so a mostly vertical move is
# simply slower. Foam is cut at 100-500 mm/min anyway.
$110=750.0
$111=137.9
$112=750.0
$113=137.9

# --- acceleration, mm/s^2 -------------------------------------------------
$120=200.0
$121=200.0
$122=200.0
$123=200.0

# --- max travel, mm -------------------------------------------------------
# Not used by grbl without homing ($20 needs $22). foamcut setup --phases travel
# measures the real values into config/machine.json, which foamcut run enforces.
$130=400.0   # placeholder
$131=300.0   # placeholder
$132=400.0   # placeholder
$133=300.0   # placeholder

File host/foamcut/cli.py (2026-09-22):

"""foamcut - command line front end for the foam cutter bring-up.

The `check` and `gen` subcommands work without any hardware attached; the rest
need the board on a serial port.
"""
from __future__ import annotations

import argparse
import sys
import time
from pathlib import Path

from . import AXES, __version__
from . import gcode as gc
from . import hwtest as hwt
from . import setup as wiz
from .grbl import Grbl, GrblAlarm, GrblError
from . import homing as hm
from .machine import DEFAULT_PATH as MACHINE_PATH
from .machine import Machine
from .link import LinkError, find_port, list_ports, open_link

DEFAULT_PORT = "auto"


def _open(args) -> Grbl:
    link = open_link(args.port, args.baud)
    g = Grbl(link)
    banner = g.connect()
    for line in banner:
        print(f"< {line}")
    if not g.is_grbl():
        print("warning: no grbl banner - is the hwtest firmware still flashed?",
              file=sys.stderr)
    return g


# ------------------------------------------------------------ offline cmds --
def _travel_problems(prog, machine_path) -> list[str]:
    m = Machine.load_or_none(Path(machine_path))
    if m is None or not m.has_travel():
        return []
    return m.check_extents(prog.extents())


def _load_program(args, wire_power=None):
    """Read, translate (axis letters, G64, feed after G94, wire S) and parse."""
    raw = Path(args.file).read_text(errors="replace")
    m = Machine.load_or_none(Path(args.machine))
    default_feed = m.cut_feed if m else 300.0
    text, notes = gc.translate(raw, preset=args.format, wire_power=wire_power,
                               default_feed=default_feed)
    for n in notes:
        print(f"  umgesetzt: {n}")
    return text, gc.Program.parse(text)


def cmd_convert(args) -> int:
    """Write the grbl-ready translation of a generator's file."""
    text, prog = _load_program(args, wire_power=args.wire)
    Path(args.out).write_text(text)
    print(prog.report())
    print(f"geschrieben: {args.out}")
    return 1 if prog.errors else 0


def cmd_check(args) -> int:
    text, prog = _load_program(args)
    print(f"{args.file}:")
    print(prog.report())
    problems = _travel_problems(prog, args.machine)
    for p in problems:
        print(f"  VERFAHRWEG: {p}")
    return 1 if (prog.errors or problems) else 0


def cmd_gen(args) -> int:
    if args.what == "square":
        text = gc.gen_square(args.size, args.feed)
    elif args.what == "taper":
        text = gc.gen_taper(args.size, args.size / 2, args.size * 0.8, args.feed)
    else:
        text = gc.gen_axis_bounce(args.axis, args.size, args.feed)
    if args.out:
        Path(args.out).write_text(text)
        print(f"wrote {args.out}")
    else:
        sys.stdout.write(text)
    return 0


# ------------------------------------------------------------- online cmds --
def cmd_probe(args) -> int:
    """Say what is on the serial port, without assuming which firmware."""
    ports = list_ports()
    if not ports:
        print("kein serieller Port da.")
        print("  - USB-Kabel steckt? (Datenkabel, nicht nur Ladekabel)")
        print("  - 12/24 V Netzteil an?")
        print("  - Board-LEDs an? Wenn nicht, liegt es an der Versorgung.")
        return 1
    print("Ports: " + ", ".join(ports))
    port = find_port(args.port)
    print(f"pruefe {port} ...")
    try:
        link = open_link(port, args.baud)
    except LinkError as e:
        print(f"  {e}")
        return 1
    try:
        banner = [l for l in link.drain() if l]
        # '?' is answered by both firmwares in their own way: grbl with a
        # <...> status report, hwtest with its command list.
        # A DTR reset leaves junk bytes in the board's line buffer; an empty
        # line flushes them (both firmwares answer it with a plain 'ok').
        link.write_raw(b"\n")
        time.sleep(0.3)
        link.drain()
        link.write_raw(b"?\n")
        deadline = time.monotonic() + 2.0
        while time.monotonic() < deadline:
            l = link.read_line(timeout=0.3)
            if l is None:
                continue
            banner.append(l)
            if l == "ok" or l.startswith("<"):
                break
        banner = [l for l in banner if l and not l.startswith("unknown command")]
        if not banner:
            print("  keine Antwort: der USB-Wandler meldet sich, der ATmega")
            print("  schweigt. Versorgung, USB-Kabel oder Bootloader pruefen -")
            print("  siehe docs/bringup.md, Abschnitt 'Board meldet sich nicht'.")
            return 1
        for line in banner[:3]:
            print(f"  < {line}")
        if any(l.startswith("Grbl") or l.startswith("<") for l in banner):
            print("  -> grbl laeuft. Weiter mit 'foamcut gui' oder 'foamcut selftest'.")
        elif any("foamcut hwtest" in l or l.startswith("commands:") for l in banner):
            print("  -> hwtest-Firmware laeuft. Weiter mit 'foamcut hwtest' oder 'make grbl-flash'.")
        else:
            print("  -> unbekannte Firmware (Marlin?).")
        return 0
    finally:
        link.close()


def cmd_status(args) -> int:
    g = _open(args)
    st = g.status()
    print(f"state: {st['state']}")
    for a, v in st.get("mpos", {}).items():
        print(f"  {a}: {v:9.3f}")
    g.link.close()
    return 0


def cmd_pins(args) -> int:
    """Watch the limit inputs: poll status reports and print every change of
    the Pn field. Press each switch in turn to learn which axis it is on."""
    g = _open(args)
    print(f"$5 (Schalter invertiert) = {g.settings().get(5, 0):g}   -"
          " Oeffner ohne $5=1 stehen dauerhaft in Pn, beim Druecken verschwindet der Buchstabe")
    print(f"beobachte {args.seconds:g} s, Strg-C beendet")
    last = None
    deadline = time.monotonic() + args.seconds
    try:
        while time.monotonic() < deadline:
            st = g.status()
            pins = st.get("pn", "")
            if pins != last:
                stamp = time.strftime("%H:%M:%S")
                print(f"  {stamp}  Pn: {pins or '-':6}  ({st['state']})")
                last = pins
            time.sleep(0.15)
    except KeyboardInterrupt:
        pass
    g.link.close()
    return 0


def cmd_settings(args) -> int:
    g = _open(args)
    if args.settings_action == "dump":
        for num, val in sorted(g.settings().items()):
            print(f"${num}={val:g}")
    else:
        applied = g.apply_settings(Path(args.file).read_text())
        for line in applied:
            print(f"> {line}")
        print(f"{len(applied)} settings applied")
    g.link.close()
    return 0


def cmd_jog(args) -> int:
    g = _open(args)
    axis = args.axis.upper()
    if axis not in AXES:
        print(f"axis must be one of {', '.join(AXES)}", file=sys.stderr)
        return 2
    g.command(f"$J=G91 G21 {axis}{args.distance:g} F{args.feed:g}")
    g.wait_idle(timeout=120)
    print(g.status()["mpos"])
    g.link.close()
    return 0


def cmd_wire(args) -> int:
    g = _open(args)
    g.hotwire(args.power)
    print(f"hot wire set to S{args.power}")
    g.link.close()
    return 0


def cmd_run(args) -> int:
    text, prog = _load_program(args, wire_power=args.wire)
    print(prog.report())
    problems = _travel_problems(prog, args.machine)
    for p in problems:
        print(f"  VERFAHRWEG: {p}")
    if (prog.errors or problems) and not args.force:
        print("refusing to run this file (use --force)", file=sys.stderr)
        return 1
    if problems:
        print("hinweis: Verfahrwegpruefung setzt voraus, dass Arbeitsnull der "
              "Referenzpunkt ist (foamcut ref)")

    g = _open(args)
    try:
        def show(i, line):
            print(f"[{i}] {line}")
        g.stream(text.splitlines(), progress=show if args.verbose else None)
        g.wait_idle()
        print("done")
    except (GrblError, GrblAlarm) as e:
        print(f"aborted: {e}", file=sys.stderr)
        g.link.write_raw(b"\x18")  # soft reset, stops motion and the hot wire
        return 1
    finally:
        g.link.close()
    return 0


def _wizard(args) -> tuple[Grbl, wiz.Wizard]:
    g = _open(args)
    if not g.is_grbl():
        g.link.close()
        raise LinkError("foamcut setup braucht grbl auf dem Board: make grbl-flash")
    m = Machine.load_or_none(Path(args.machine)) or Machine()
    axes = tuple(a.upper() for a in getattr(args, "axes", None) or AXES)
    bad = [a for a in axes if a not in AXES]
    if bad:
        g.link.close()
        raise LinkError(f"--axes: unbekannt {bad}, erlaubt X Y U V")
    w = wiz.Wizard(g, m, wiz.Console(), jog_mm=getattr(args, "jog_mm", 20.0), axes=axes)
    spmm = getattr(args, "spmm", None)
    if spmm:
        print(f"setze Startwert {spmm:g} Schritte/mm auf allen Achsen ($100..$103)")
        for i, a in enumerate(AXES):
            g.set_setting(100 + i, spmm)
            m.steps_per_mm[a] = spmm
    return g, w


def cmd_setup(args) -> int:
    """Measure the machine: mapping, steps/mm, direction, reference, travel."""
    g, w = _wizard(args)
    try:
        rc = w.run(phases=args.phases)
        if rc == 0:
            path = w.machine.save(Path(args.machine))
            print(f"gespeichert: {path}")
        return rc
    except wiz.Abort as e:
        print(f"\n{e}", file=sys.stderr)
        return 1
    finally:
        g.link.close()


def cmd_ref(args) -> int:
    """Manual referencing only - the thing to do after every power-up."""
    g, w = _wizard(args)
    try:
        w._prepare()
        w.phase_reference()
        return 0
    except wiz.Abort as e:
        print(f"\n{e}", file=sys.stderr)
        return 1
    finally:
        g.link.close()


def cmd_home(args) -> int:
    """Homing cycle on the switches, then the work origin from the offsets."""
    m = Machine.load_or_none(Path(args.machine))
    if not m or not m.homing.enabled:
        print("Endschalter sind nicht konfiguriert: foamcut homing set --enable ...", file=sys.stderr)
        return 1
    g = _open(args)
    try:
        for k, v in m.grbl_settings().items():      # make sure the board agrees
            g.set_setting(k, v)
        print("Referenzfahrt ...")
        mpos = hm.reference(g, m.homing)
        m.save(Path(args.machine))
        print("Maschinenposition am Schalter:", "  ".join(f"{a}{mpos[a]:.3f}" for a in AXES))
        st = g.status()
        print("Arbeitsposition jetzt:       ", "  ".join(f"{a}{st['mpos'][a] - m.homing.work_origin(mpos)[a]:.3f}" for a in AXES))
        return 0
    except (GrblError, GrblAlarm, TimeoutError, RuntimeError) as e:
        print(f"Referenzfahrt fehlgeschlagen: {e}", file=sys.stderr)
        return 1
    finally:
        g.link.close()


def _parse_axis_values(items) -> dict[str, float]:
    out = {}
    for item in items or []:
        axis, _, val = item.partition("=")
        axis = axis.strip().upper()
        if axis not in AXES:
            raise ValueError(f"Achse muss X, Y, U oder V sein: {item!r}")
        out[axis] = float(val.replace(",", "."))
    return out


def cmd_homing(args) -> int:
    """Show or edit the limit switch configuration (no hardware needed)."""
    path = Path(args.machine)
    m = Machine.load_or_none(path) or Machine()
    h = m.homing
    if args.homing_action == "set":
        try:
            offsets = _parse_axis_values(args.offset)
            lengths = _parse_axis_values(args.length)
        except ValueError as e:
            print(f"error: {e}", file=sys.stderr)
            return 2
        if args.enable:
            h.enabled = True
        if args.disable:
            h.enabled = False
        if args.nc:
            h.invert_switch = True
        if args.no:
            h.invert_switch = False
        if args.pulloff is not None:
            h.pulloff = args.pulloff
        if args.no_soft_limits:
            h.soft_limits = False
        h.offset_mm.update(offsets)
        h.length_mm.update(lengths)
        if h.enabled and not all(h.length_mm[a] > 0 for a in AXES):
            print("warnung: nicht alle Laengen gesetzt (--length X=.. Y=.. U=.. V=..)", file=sys.stderr)
        m.save(path)
        print(f"gespeichert: {path}")
    print(f"Endschalter: {'AN' if h.enabled else 'aus'}   Schalter: {'Oeffner (NC)' if h.invert_switch else 'Schliesser (NO)'}"
          f"   Pull-off {h.pulloff:g} mm   Softlimits {'an' if h.soft_limits else 'aus'}")
    print("  Achse  Laenge ab Schalter  Versatz +  nutzbar")
    for a in AXES:
        print(f"    {a}    {h.length_mm[a]:10.1f} mm   {h.offset_mm[a]:7.2f}   {h.usable_travel(a):7.1f} mm")
    if h.home_mpos:
        print("  letzte Referenzfahrt, MPos:", "  ".join(f"{a}{h.home_mpos[a]:.3f}" for a in AXES))
    return 0


def cmd_machine(args) -> int:
    """Show or set machine-level numbers that no wizard measures."""
    path = Path(args.machine)
    m = Machine.load_or_none(path) or Machine()
    if args.machine_action == "set":
        if args.tower_gap is not None:
            if args.tower_gap <= 0:
                print("error: tower gap muss > 0 sein", file=sys.stderr)
                return 2
            m.tower_gap_mm = args.tower_gap
            m.tower_gap_measured = True
        if args.wire_fixed is not None:
            m.wire_fixed_tower = args.wire_fixed
        if args.feed is not None:
            m.cut_feed = args.feed
        if args.wire is not None:
            m.wire_power = args.wire
        if args.warmup is not None:
            m.warmup_s = args.warmup
        for item in args.steps or []:
            a, _, v = item.partition("=")
            a = a.strip().upper()
            try:
                if a not in AXES or float(v) <= 0:
                    raise ValueError
            except ValueError:
                print(f"error: --steps erwartet ACHSE=WERT, z.B. Y=17408 (nicht {item!r})", file=sys.stderr)
                return 2
            m.steps_per_mm[a] = float(v)
        if args.kerf is not None:
            if args.kerf < 0:
                print("error: kerf muss >= 0 sein", file=sys.stderr)
                return 2
            m.kerf_mm = args.kerf
        m.save(path)
        print(f"gespeichert: {path}")
    print(f"Turmabstand (Drahtaufhaengungen): {m.tower_gap_mm:g} mm"
          + ("" if m.tower_gap_measured else "   <- NICHT gemessen, Platzhalter"))
    print(f"Draht fest an Turm {m.wire_fixed_tower} ({'X/Y' if m.wire_fixed_tower == 1 else 'U/V'}), "
          "dort liegt die Fluegelwurzel")
    print(f"Schnitt: Vorschub {m.cut_feed:g} mm/min, Draht S{m.wire_power} (0 = GUI-Schieber), "
          f"Aufheizen {m.warmup_s:g} s, Schnittbreite (Kerf) {m.kerf_mm:g} mm")
    for note in m.clamp_rates():
        print("  " + note)
    print("Schritte/mm:", "  ".join(f"{a} {m.steps_per_mm[a]:g}" for a in AXES))
    print("Max mm/min: ", "  ".join(f"{a} {m.max_rate[a]:g}" for a in AXES))
    print("Verfahrweg: ", "  ".join(f"{a} {m.travel_mm[a]:g}" for a in AXES))
    return 0


def cmd_jogpad(args) -> int:
    """Keyboard jogging, nothing else."""
    g, w = _wizard(args)
    try:
        w._prepare()
        pos = w.jogpad("Freies Verfahren. Enter beendet.")
        print("Position:", "  ".join(f"{a}{v:.3f}" for a, v in pos.items()))
        return 0
    except wiz.Abort as e:
        print(f"\n{e}", file=sys.stderr)
        return 1
    finally:
        g.link.close()


def cmd_wing(args) -> int:
    """Generate one-pass XYUV G-code for a wing panel from a .wing spec."""
    from .wing import WING_MODEL
    return _cmd_design(args, WING_MODEL, "wing")


def cmd_shape(args) -> int:
    """Generate one-pass XYUV G-code for a free shape (disc or ring) from a .shape spec."""
    from .shape import SHAPE_MODEL
    return _cmd_design(args, SHAPE_MODEL, "shape")


def cmd_contour(args) -> int:
    """Generate a prismatic (X=U, Y=V) program for the outlines of an SVG from a .contour spec."""
    from .contour import CONTOUR_MODEL
    return _cmd_design(args, CONTOUR_MODEL, "contour")


def cmd_slices(args) -> int:
    """Generate the program for one slab of an STL body from a .slices spec."""
    from .slices import SLICE_MODEL
    return _cmd_design(args, SLICE_MODEL, "slices")


def cmd_esp(args) -> int:
    """Programs on an ESP32/ESP3D in front of the board: list, upload, start, watch."""
    from .esp import Esp3d, EspError
    e = Esp3d(args.host)
    try:
        if args.esp_action == "ls":
            jobs = e.jobs()
            if not jobs:
                print("keine Programme im ESP-Flash")
            for j in jobs:
                print(f"{j.name:32s} Block {j.block or '?':>12s}  X={j.x or '?':>4s} Tisch Y={j.y or '?':>4s}  "
                      f"Wurzel {j.root or '?'}  {j.time or '?'}  {j.title}")
        elif args.esp_action == "put":
            for f in args.files:
                print(e.upload(Path(f)).strip() or f"hochgeladen: {f}")
        elif args.esp_action == "start":
            print(e.start(args.files[0]).strip())
        elif args.esp_action in ("pause", "resume", "abort"):
            print(e.stream(args.esp_action))
        else:
            st = e.stream()
            print(st)
    except EspError as err:
        print(f"error: {err}", file=sys.stderr)
        return 1
    except IndexError:
        print("error: Dateiname fehlt", file=sys.stderr)
        return 2
    return 0


def cmd_nest(args) -> int:
    """Several parts in one block from a .batch list -> one program."""
    from . import nest as ns
    from .wing import WingError
    if args.template:
        sys.stdout.write(ns.Batch(items=[ns.Item("mein.wing", True), ns.Item("rumpf.shape")]).to_text())
        return 0
    if not args.batch:
        print("foamcut nest LISTE.batch -o OUT.nc   oder   foamcut nest --template > liste.batch", file=sys.stderr)
        return 2
    m = Machine.load_or_none(Path(args.machine)) or Machine()
    try:
        batch = ns.Batch.parse(Path(args.batch).read_text(), Path(args.batch).parent)
        code, nest = ns.generate(batch, m, Path(args.airfoils))
    except (WingError, OSError, ValueError) as e:
        print(f"error: {e}", file=sys.stderr)
        return 1
    for n in nest.notes:
        print(f"  {n}")
    ext = nest.extents()
    print("  Schlittenweg: " + "  ".join(f"{a} {lo:.1f}..{hi:.1f}" for a, (lo, hi) in ext.items()))
    problems = m.check_extents(ext) if m.has_travel() else []
    for pr in problems:
        print(f"  VERFAHRWEG: {pr}")
    prog = gc.Program.parse(code)
    for e in prog.errors:
        print(f"  ERROR: {e}")
    out = Path(args.out) if args.out else Path(args.batch).with_suffix(".nc")
    out.write_text(code)
    print(f"geschrieben: {out}")
    return 1 if (problems or prog.errors) else 0


def _cmd_design(args, model, cmd: str) -> int:
    from .wing import WingError
    if args.template:
        sys.stdout.write(model.template)
        return 0
    if not args.spec:
        print(f"foamcut {cmd} SPEC.{cmd} -o OUT.nc   oder   foamcut {cmd} --template > mein.{cmd}", file=sys.stderr)
        return 2
    m = Machine.load_or_none(Path(args.machine)) or Machine()
    try:
        spec = model.parse(Path(args.spec).read_text())
        code, path = model.generate(spec, m, Path(args.airfoils))
    except (WingError, OSError, ValueError) as e:
        print(f"error: {e}", file=sys.stderr)
        return 1
    for n in path.notes:
        print(f"  {n}")
    ext = path.extents()
    print("  Schlittenweg: " + "  ".join(f"{a} {lo:.1f}..{hi:.1f}" for a, (lo, hi) in ext.items()))
    problems = m.check_extents(ext) if m.has_travel() else []
    for pr in problems:
        print(f"  VERFAHRWEG: {pr}")
    prog = gc.Program.parse(code)
    for e in prog.errors:
        print(f"  ERROR: {e}")
    stl = getattr(args, "stl", None)
    if stl is not None and model.stl:
        target = Path(stl) if stl else Path(args.spec).with_suffix(".stl")
        target.write_bytes(model.stl(spec, m, Path(args.airfoils)))
        print(f"geschrieben: {target}")
    out = Path(args.out) if args.out else Path(args.spec).with_suffix(".nc")
    programs = list(getattr(path, "programs", []) or [])
    if len(programs) > 1:                   # one file per foam board
        for k, (_, board_code) in enumerate(programs, start=1):
            target = out.with_name(f"{out.stem}_platte{k}.nc")
            target.write_text(board_code)
            print(f"geschrieben: {target}")
    else:
        out.write_text(code)
        print(f"geschrieben: {out}")
    return 1 if (problems or prog.errors) else 0


def cmd_sim(args) -> int:
    """Simulate a program: both carriage paths drawn turtle-style, no hardware."""
    import tkinter as tk
    from .gui_sim import open_sim_window
    text, prog = _load_program(args)
    m = Machine.load_or_none(Path(args.machine)) or Machine()
    root = tk.Tk()
    root.withdraw()
    win = open_sim_window(root, text.splitlines(), m, Path(args.file).name)
    win.protocol("WM_DELETE_WINDOW", root.destroy)
    root.mainloop()
    return 0


def cmd_gui(args) -> int:
    """The graphical interface: Qt by default, the older Tk one with --tk."""
    if args.tk:
        from .gui import run_gui
        return run_gui(args.port, args.baud, Path(args.machine))
    try:
        from .qt.mainwindow import run
    except ImportError as e:
        print(f"PyQt6 fehlt ({e}); starte die Tk-Oberflaeche. pip install PyQt6", file=sys.stderr)
        from .gui import run_gui
        return run_gui(args.port, args.baud, Path(args.machine))
    return run(args.port, args.baud, Path(args.machine))
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

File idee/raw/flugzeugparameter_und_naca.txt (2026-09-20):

### id: 69bc11c1-5da4-8329-8c64-0045a5e252d4
### title: Flugzeugparameter und NACA
### create: 1773933057.885426
### update: 1774447534.334713
=== user 1773933054.74 ===
für diesen Code bitte parameter des Flugzeugs angeben, bzw direct als funktionen implementieren, aus denen man die NACA parameter berehcnet/schätzt:

```python
import numpy as np
import matplotlib.pyplot as plt

# =======================
# Konstanten / Parameter
# =======================
CHORD_LENGTH_M = 0.2 # Flügeltiefe der Rippe in Metern
NUM_POINTS = 50 # Anzahl Punkte zur Profilkontur
NACA_MAX_CAMBER = 0.02 # maximale Wölbung (m)
NACA_CAMBER_POS = 0.4 # Position der maximalen Wölbung (p)
NACA_THICKNESS = 0.12 # maximale Dicke (t)
OUTPUT_PLOT = True # True: zeigt Plot der Rippe
OUTPUT_SVG = "rippe.svg" # Dateiname für SVG
OUTPUT_DXF = "rippe.dxf" # Dateiname für DXF

# =======================
# Funktionen
# =======================
def generate_naca4_airfoil(max_camber, camber_pos, thickness, chord=1.0, points=50):
····"""
····Berechnet x,y-Koordinaten für ein NACA4-Profil
····"""
····x = np.linspace(0, chord, points)
····# Dickenverteilung
····yt = 5 * thickness * chord * (
········0.2969 * np.sqrt(x/chord)
········- 0.1260 * (x/chord)
········- 0.3516 * (x/chord)**2
········+ 0.2843 * (x/chord)**3
········- 0.1015 * (x/chord)**4
····)
····# Mittellinie
····yc = np.zeros_like(x)
····for i in range(points):
········if x[i] < camber_pos * chord:
············yc[i] = max_camber / camber_pos**2 * (2*camber_pos*(x[i]/chord) - (x[i]/chord)**2)
········else:
············yc[i] = max_camber / (1-camber_pos)**2 * ((1-2*camber_pos) + 2*camber_pos*(x[i]/chord) - (x[i]/chord)**2)

····theta = np.arctan(np.gradient(yc, x))
····# obere und untere Fläche
····xu = x - yt * np.sin(theta)
····yu = yc + yt * np.cos(theta)
····xl = x + yt * np.sin(theta)
····yl = yc - yt * np.cos(theta)

····# Verbinden für durchgehende Kontur (Tip->Root->Tip)
····x_full = np.concatenate([xu[::-1], xl[1:]])
····y_full = np.concatenate([yu[::-1], yl[1:]])
····return x_full, y_full

def plot_airfoil(x_coords, y_coords):
····plt.plot(x_coords, y_coords, color="blue")
····plt.axis("equal")
····plt.title("NACA4 Rippe")
····plt.xlabel("x [m]")
····plt.ylabel("y [m]")
····plt.show()

# =======================
# Hauptprogramm
# =======================
if __name__ == "__main__":
····x_coords, y_coords = generate_naca4_airfoil(
········max_camber=NACA_MAX_CAMBER,
········camber_pos=NACA_CAMBER_POS,
········thickness=NACA_THICKNESS,
········chord=CHORD_LENGTH_M,
········points=NUM_POINTS
····)

····if OUTPUT_PLOT:
········plot_airfoil(x_coords, y_coords)

····# Optional: SVG export
····try:
········import svgwrite
········dwg = svgwrite.Drawing(OUTPUT_SVG, profile='tiny', size=(f"{CHORD_LENGTH_M*1000}mm", f"{CHORD_LENGTH_M*1000}mm"))
········points_svg = [(x*1000, -y*1000) for x, y in zip(x_coords, y_coords)] # mm, y invertiert
········dwg.add(dwg.polyline(points_svg, stroke='black', fill='none', stroke_width=1))
········dwg.save()
········print(f"SVG gespeichert: {OUTPUT_SVG}")
····except ImportError:
········print("svgwrite nicht installiert, SVG wird nicht erzeugt.")

····# Optional: DXF export
····try:
········import ezdxf
········doc = ezdxf.new()
········msp = doc.modelspace()
········for i in range(len(x_coords)-1):
············msp.add_line((x_coords[i]*1000, y_coords[i]*1000), (x_coords[i+1]*1000, y_coords[i+1]*1000))
········doc.saveas(OUTPUT_DXF)
········print(f"DXF gespeichert: {OUTPUT_DXF}")
····except ImportError:
········print("ezdxf nicht installiert, DXF wird nicht erzeugt.")
```
aus
=== assistant 1773933057.804788 ===
Alles klar! Wir können deinen Code so erweitern, dass die Parameter des Flugzeugs direkt über Funktionen berechnet oder geschätzt werden, z. B. basierend auf Spannweite, Flügelfläche, gewünschtem Auftriebsbeiwert usw. Außerdem kann die NACA-4-Ziffer automatisch aus diesen Parametern abgeleitet werden. Ich habe deinen Code dafür angepasst:

```python
import numpy as np
import matplotlib.pyplot as plt

# =======================
# Flugzeug-Parameter Funktionen
# =======================
def estimate_chord(area, span):
····"""
····Schätzt die mittlere Flügeltiefe (Chord) aus Fläche und Spannweite
····A = b * c_mean
····"""
····return area / span

def estimate_naca_parameters(design_cl=0.5, thickness_ratio=0.12):
····"""
····Schätzt NACA-4-Ziffernparameter:
····max_camber (m), camber_pos (p), thickness (t)
····design_cl: gewünschter Auftriebsbeiwert ~0.5-1.2 für Modellflugzeug
····thickness_ratio: relative maximale Dicke
····"""
····# Faustregel: max_camber ~ CL / 6
····max_camber = design_cl / 6
····# Position der maximalen Wölbung (p) ~ 0.4-0.5 für moderate Profile
····camber_pos = 0.4
····thickness = thickness_ratio
····return max_camber, camber_pos, thickness
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

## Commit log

2026-09-20 foamcut: XYUV hot-wire cutter host, firmware overlay and docs
    Host (host/foamcut): grbl link/worker, Qt GUI (Maschine, Flügel, Formen,
    Programm & Sim mit Live-Lauf), Flügelgenerator (Profil, Ruderschnitt,
    Fläche->Tiefen, Spiegel), freie Formen (Scheibe/Ring), Freischnitt mit
    Turm-2-Versatz, Tisch/Block/Mindestblock, Endschalter-Homing mit Nullpunkt-
    Versatz und Schalterwächter, CLI. Firmware: grbl-Mega-5X-Overlay für die
    GT2560 (Pinmap X/Y/U/V, Endschalter auf X_MIN/X_MAX/Y_MIN/Y_MAX, NC-Umkehr),
    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
    [flugzeugparameter_und_naca.txt, grbl_settings_foamcut.txt, machine.json]
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2026-09-21 Qt-GUI auf Designer-.ui-Dateien umgestellt, Fensterbreite verkleinert
    Masken liegen jetzt in host/foamcut/qt/ui/*.ui (uic.loadUi); Code baut nur
    noch dynamische Teile (Formulare aus FIELDS, Jog-Pads, Diagramme) in benannte
    Platzhalter-Layouts. Diagramme bekommen einen ViewFrame: Titel + Rasterangabe
    als Labels in einer Zeile ueber der Zeichenflaeche statt hineingemalt.
    Breite: Vorschub in eigene Zeile, Jog-Tasten und Hilfetexte/Meldungen mit
    Ignored-Breite, Expanding-Spacer ohne Mindestbreite, Ebenen in 4 Spalten.
    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
    [machine.json]
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2026-09-21 Vorschub, Heizleistung und Aufheizzeit ebenfalls in die Maschine
    Wie der Kerf: machine.cut_feed, wire_power, warmup_s gelten fuer Fluegel,
    Formen, Stapel und Freischnitt. Eingabe im Block "Heizdraht und Schnitt"
    der Maschinenseite (Schieber = Heizleistung, wird beim Loslassen
    gespeichert) oder `foamcut machine set --feed/--wire/--warmup/--kerf`.
    Die Felder feed/wire/warmup sind aus [schnitt] der .wing/.shape-Dateien
    und aus der Schachtel-Liste raus; alte Dateien laden weiter (ueberlesen).
    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
    [machine.json]
2026-09-21 Draht erst bei X0/U0 ausschalten
    Rueckfahrt G0 X0 U0 mit heissem Draht, dann M5, dann senken. Liegt der
    Block weiter hinten als angegeben, klebte der kalte Draht sonst im Schaum
    fest (Valentin, 2026-09-22). Gilt fuer Fluegel, Formen und Stapel; der
    Freischnitt bleibt (schaltet nach dem letzten Schnittsegment ab).
    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
    [machine.json]
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2026-09-21 machine.json: Schnittwerte vom Heissdraht-Erstlauf am Board (12 V, 15 Ohm/m)
    Vorschub 100 mm/min, S100, Kerf 4 mm - so eingestellt beim ersten Schnitt
    ueber den HEATER_1-Ausgang (Valentin, 2026-09-22).
    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
    [machine.json]
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2026-09-22 Scheiben: STL-Koerper in Scheiben, verlaufend zwischen beiden Schnittflaechen
    Neues Modell .slices (Seite "Scheiben", `foamcut slices`, auch im
    Schachteln): STL binaer/ASCII ohne Abhaengigkeiten gelesen, Ebene-Netz-
    Schnitt zu geschlossenen Umrissen (auch durch Netzknoten), Scheibe n einer
    Dicke entlang waehlbarer Achse mit waehlbarer Oben-Achse. Verlaufend: Seite
    A = Schnitt am Anfang, B = am Ende, gleich viele Punkte je Umriss ab dem
    hintersten Punkt, Loecher per Schlitz (Ring-Schema) -> glatte Regelflaeche
    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
    [beispiel.stl]
2026-09-22 Host fuer den ESP32 vorbereitet: tcp://-Verbindung und Job-Kopfzeile
    - link.open_link(): tcp://host[:port] oeffnet einen TcpLink (ESP3D-Bruecke,
    Port 23), sonst wie bisher die serielle Schnittstelle; GUI-Portfeld und
    --port nehmen beides. Ueber TCP wird das Board beim Verbinden nicht
    resettet, connect() holt den Banner per Soft-Reset.
    - Jede erzeugte .nc traegt in Zeile 2 "; foamcut-job block=LxHxB x= y=
    root=T s= time= travel=" - Block, Lage, Tisch und Laufzeit lesbar ohne
    foamcut (Programmseite auf dem ESP32).
    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
    [cli.py, link.py, nest.py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]
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2026-09-22 Teile in einer Kette schneiden: obere zuerst, Einstieg wo der Draht steht
    route_parts: kein Rueckweg mehr zu einem Port hinten je Teil. Reihenfolge
    (cut_order): hoechste Teile zuerst - ein freigeschnittenes Teil kann fallen -
    und innerhalb einer Hoehenlage das naechstgelegene, also hin und zurueck
    durch die Reihen. Einstieg am Umrisspunkt, der dem Draht am naechsten ist
    (geschlossener Umlauf wird dort gestartet, Loecher/Schlitze bleiben; beim
    verlaufenden Schnitt beide Seiten am selben Index). Verlassen ueber den
    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
    [machine.json]
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2026-09-22 Eng gepackte Nachbarn blockieren die Wegsuche nicht mehr
    Ein Schnitt kann in mehrere Umrisse zerfallen (Karosserie und Raeder), die
    naeher beieinander liegen als der Fahrweg-Abstand; deren Abstandsringe
    ueberlappen. Bisher brach die Wegsuche dann mit "Teil ist von anderen so eng
    umgeben" ab, obwohl der Draht den Ring nur streifen wuerde. Jetzt:
    geom.route() laesst Hindernisse fallen, in deren Ring Start oder Ziel schon
    stehen; _port() und die Ausstiegspunkte verbieten nur Punkte im Umriss eines
    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
    [racecar.stl]
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2026-09-22 Holme: sechs Zeilen statt einer, Nut senkrecht auf der Haut
    Der Fehler: im Spec-Format ist ';' das Kommentarzeichen, also ueberlebte von
    "30% oben 6x4; 40% unten 5x4" nur der erste Holm den Weg durch
    to_text/parse - mehrere Holme und alles nach dem ersten Semikolon fielen weg.
    Jetzt sechs eigene Felder holm1..holm6, je eine Leiste, leere ignoriert; die
    alte Zeile `spars` wird weiter gelesen.
    Nutrichtung: geom.notch_normal schneidet die Nut senkrecht auf die Haut an
    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
    [machine.json]
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2026-09-23 Scheiben verlaufend als Normalfall, Plattenlage von der Software
    Der prismatische Schnitt war mein Missverstaendnis: Scheiben sollen wie alles
    andere geschnitten werden - beide Achsen unabhaengig, die beiden Schnitt-
    flaechen duerfen verschieden sein, damit ein konischer Rumpf bei 20 mm Dicke
    auch seinen Winkel bekommt.
    - Der verlaufende Schnitt kann jetzt mehrere Umrisse je Flaeche: _match()
    paart sie ueber die Mittelpunkte (Karosserie zu Karosserie, Rad zu Rad),
    _pair_loft arbeitet je Paar. Passen die Flaechen nicht zusammen (andere
    Anzahl Umrisse oder Loecher), sagt die Meldung das und nennt die beiden
    Auswege: duennere Scheiben oder 'verlaufend = nein'.
    - "Seite A ab Turm" darf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
    [slices.py]
2026-09-23 Prismatischer Schnitt sagt, wie viel Winkel er wegwirft
    Der Schalter "Verlaufend" bleibt leicht auf "nein" stehen (die Seite merkt
    sich die letzten Werte), und dann sehen beide Enden gleich aus, ohne dass
    etwas darauf hinweist. Jetzt vergleicht der prismatische Zweig die beiden
    Schnittflaechen und schreibt bei mehr als 0,5 mm Unterschied in die Notizen,
    um wie viel sie sich unterscheiden und dass 'Verlaufend = ja' der Scheibe
    ihren Winkel gibt.
    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
    [rippen2.stl]
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2026-10-07 Leeres Endprofil nicht als Dateiname nehmen
    "Profil am Ende" darf leer bleiben (= wie an der Wurzel). Ueber die Maske
    fuellt parse() das Feld, direkt aufgerufen lief build_path aber mit "" in
    die Dateisuche: Path("") ist das Arbeitsverzeichnis, exists() sagt ja, und
    load() stolperte ueber IsADirectoryError. Jetzt faellt build_path auf das
    Wurzelprofil zurueck, surfaces() weist leere Namen ab und prueft is_file()
    statt exists(). Der G-Code-Kopf nennt in dem Fall das Wurzelprofil.
    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
    [airfoil.py, wing.py]
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
